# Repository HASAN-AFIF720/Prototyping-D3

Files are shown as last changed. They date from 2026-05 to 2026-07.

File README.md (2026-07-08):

# Prototyping-D3 — Autonomous 2WD Robot Vehicle






An **untethered, two-wheel-drive robot car** that operates as a hybrid **line follower** and **obstacle avoider**. The vehicle follows a strict safety-first priority: obstacle detection (safety) always overrides line tracking (navigation).

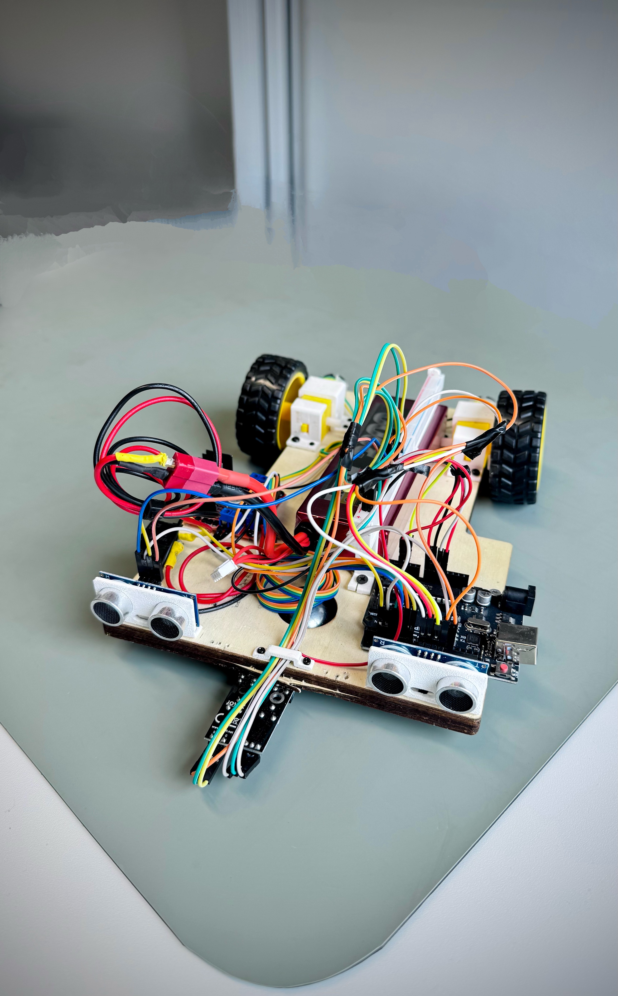
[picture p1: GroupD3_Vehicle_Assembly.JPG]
Assembled vehicle


---

## Overview

Built for the Systems Engineering / Prototyping module at **Hochschule Hamm-Lippstadt**, this project pairs a formal **SysML model** with a physically assembled Arduino prototype. Every loop follows a *Sense → Think → Act* pipeline: read the ultrasonic sensors first, and only fall through to IR line tracking when the path ahead is clear.

**Key features**

- Hybrid **line following + obstacle avoidance** on a single Arduino UNO
- **Safety-first priority gate** — obstacle avoidance pre-empts navigation every cycle
- **Dual HC-SR04** front sensors for obstacle detection and evasive manoeuvres
- **Dual downward IR** sensors for line tracking
- **Isolated power** — motor current separated from Arduino logic supply
- Full **SysML documentation** and **custom 3D-modeled mounts**

---

## Repository Structure

| Path | Contents |
|---|---|
| [`Codes/`](Codes) | Arduino firmware — 3 sketches (final, baseline, experimental) with its own README |
| [`Design/`](Design) | Mechanical CAD parts (STEP) with its own README |
| [`Diagrams/`](Diagrams) | **Current** SysML diagram set (7 PNGs) with its own README |
| `zz_diagrams_archive/` | Superseded diagrams — kept for history only, ignore (current set is in `Diagrams/`) |
| `GroupD3_Wiring_Schematic.pdf` | Full wiring / circuit schematic |
| `GroupD3_Vehicle_Assembly.JPG` | Photo of the assembled prototype |

---

## Hardware Architecture

| Component | Part | Role |
|---|---|---|
| Microcontroller | 1× Arduino UNO (Joy-IT), 5V logic | Central decision maker |
| Motor Driver | 1× L298N Dual H-Bridge | Drives motors; ENA/ENB jumpers removed for PWM |
| Actuators | 2× DC gear motors (rubber tread) | Left / right differential drive |
| Obstacle Sensors | 2× HC-SR04 ultrasonic | Front-Left / Front-Right distance |
| Tracking Sensors | 2× IR line sensors | Downward-facing line detection |
| Power | 12V / AA battery pack | Motor power isolated from logic power |

### Pin Map

| Subsystem | Signal | Arduino Pin |
|---|---|---|
| IR line sensor — Left | digital | D12 |
| IR line sensor — Right | digital | D13 |
| Right motor | ENA (PWM) / IN1 / IN2 | D10 / D5 / D4 |
| Left motor | ENB (PWM) / IN3 / IN4 | D11 / D7 / D6 |
| Ultrasonic — Left | TRIG / ECHO | A2 / A3 |
| Ultrasonic — Right | TRIG / ECHO | D2 / D3 |

> **IR polarity:** `HIGH` = line detected (consistent across all sketches). **Obstacle threshold:** 15 cm.

---

## Control Logic (Sense → Think → Act)

The `void loop()` executes a two-tier priority hierarchy:

**Priority 1 — Obstacle Avoidance (safety)**
Read both HC-SR04 sensors. If an obstacle is detected within the **15 cm** threshold, the vehicle halts and executes an evasive manoeuvre around the object, then re-acquires and rejoins the line before resuming.

**Priority 2 — Line Tracking (navigation)**
If the path is clear, read the IR sensors and correct course — turn toward the sensor that detects the line, or drive straight when centered.

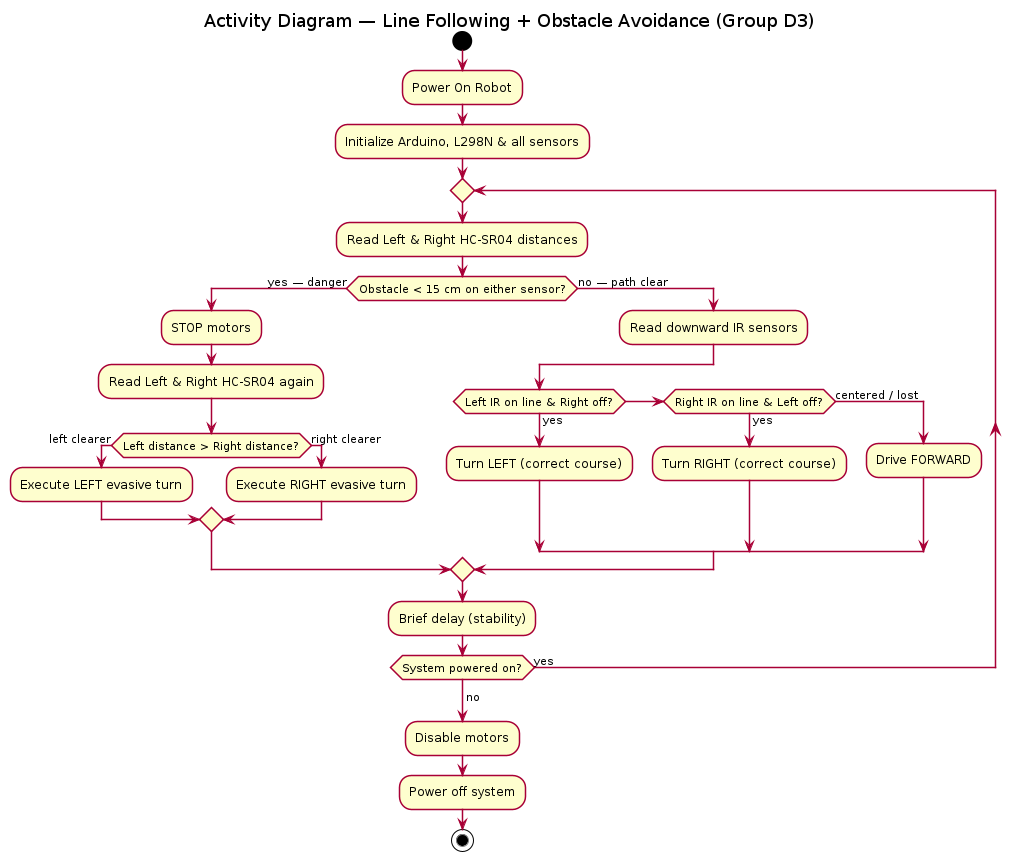
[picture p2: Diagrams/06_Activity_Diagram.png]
Control algorithm


Full behavioral and architectural models are in [`Diagrams/`](Diagrams): Requirement, BDD, IBD, Use Case, Sequence, Activity, and Package diagrams.

---

## Firmware — Build & Upload

All sketches live in [`Codes/`](Codes):

| Sketch | Purpose |
|---|---|
| `GroupD3_AutonomousVehicle_Final.ino` | **Final build** — line following + obstacle avoidance |
| `GroupD3_LineFollower_Baseline.ino` | Stable line-following baseline (Milestone 1) |
| `GroupD3_LineFollower_Fast_Experimental.ino` | Experimental higher-speed variant (reference only) |

**Steps** — requires the [Arduino IDE](https://www.arduino.cc/en/software) (1.8+ or 2.x):

1. Open `Codes/GroupD3_AutonomousVehicle_Final.ino` (the full build).
2. Select **Tools → Board → Arduino UNO**.
3. Select the correct **Port** under **Tools → Port**.
4. Wire the hardware per the Pin Map above (or `GroupD3_Wiring_Schematic.pdf`).
5. Power the L298N from the battery pack; **do not** back-feed motor voltage through the Arduino's USB.
6. Click **Upload**.

**Bench-test tips**

- Verify IR sensor polarity before driving — inverted line logic is the most common failure mode here.
- Confirm ultrasonic timing is intact (avoid Timer0 modifications, which distort `delay()`/`pulseIn()` used by HC-SR04).
- Test line following and obstacle avoidance in isolation before running the hybrid loop.

---

## Documentation

| Document | Location |
|---|---|
| Firmware (Arduino) | [`Codes/`](Codes) |
| SysML diagram set (7) | [`Diagrams/`](Diagrams) |
| Mechanical CAD (STEP) | [`Design/`](Design) |
| Circuit schematic | `GroupD3_Wiring_Schematic.pdf` |

---

## Project Milestones

- **Milestone 1 — Lane Following** ✅ Vehicle follows the track via IR line detection.
- **Milestone 2 — Obstacle Avoidance** ✅ HC-SR04 avoidance layered on the confirmed line-following base.

---

## Team — Group D3

| Member | GitHub |
|---|---|
| Md Afif Hasan | [@HASAN-AFIF720](https://github.com/HASAN-AFIF720) |
| Jubayer Ahmed | [@MainReturn0](https://github.com/MainReturn0) |
| Rei Halilaj | [@ReiHalilaj](https://github.com/ReiHalilaj) |
| Ambrose Alakweojimba |[@AmbroseDera](https://github.com/AmbroseDera)|

*Systems Engineering / Prototyping project — Hochschule Hamm-Lippstadt*

---

## License

Academic coursework, shared for educational reference. If you intend to reuse this work, please credit Group D3 and consider adding an explicit open-source license (e.g. MIT) to the repository.

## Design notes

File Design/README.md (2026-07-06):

# Prototyping-D3 — Mechanical Design (CAD)

This folder contains the custom mechanical parts for **Group D3's autonomous 2WD robot vehicle**, exported as **STEP** (ISO 10303) 3D models.

These parts are purpose-designed mounts rather than a generic kit chassis. The design goal is **alignment repeatability**: sensors sit exactly where the firmware expects them, and the motors are held rigid so the wheels react predictably. A stable mechanical base directly simplifies the control algorithm — the IR sensors stay at a fixed height and spacing, and the ultrasonic sensors keep a consistent forward-facing angle.

---

## Part Index

| # | File | Qty | Format | Purpose |
|---|---|-----|---|---|
| 1 | `GroupD3_2xIRSensor_6May2026.STEP` | 2 | STEP | Downward-facing IR line-sensor brackets (Left / Right) |
| 2 | `GroupD3_2xMotorholderPart1_6May2026.step` | 2 | STEP | DC gear-motor clamp — part 1 (Left / Right) |
| 3 | `GroupD3_2xMotorholderPart2_6May2026.step` | 2 | STEP | DC gear-motor clamp — part 2 (Left / Right) |
| 4 | `GroupD3_2xUltrasonicSensor_6May2026.STEP` | 2 | STEP | HC-SR04 ultrasonic mounts (Front-Left / Front-Right) |
| 5 | `GroupD3_8xPCBStandoff_6May2026.STEP` | 8 | STEP | Standoffs isolating and elevating the controller / driver boards |

**Total: 16 printed parts.** All exports dated 6 May 2026.

---

## Part Details

### 1 — IR Sensor Brackets (2×)
Hold the two IR line-tracking modules downward-facing at the front edge of the chassis. A fixed, equal ride-height on both sides keeps the digital line readings symmetric, which is what the steering-correction logic assumes.

### 2 & 3 — Motor Holder (2× Part 1 + 2× Part 2)
A two-piece clamp per motor that captures the DC gear motor body and bolts it rigidly to the chassis. Rigid mounting prevents the motor from shifting under load or during hard-reverse turns, protecting wheel alignment and reducing skid.

### 4 — Ultrasonic Sensor Mounts (2×)
Position the two HC-SR04 sensors at the front corners (Front-Left / Front-Right) with a consistent forward orientation, so the left/right distance comparison used for evasive turns stays meaningful.

### 5 — PCB Standoffs (8×)
Elevate and space the Arduino UNO and L298N driver above the chassis deck, keeping solder joints and pin headers clear of the surface and separating the logic board from the motor-driver board for cleaner wiring and easier fault checking.

---

## Mounts → Hardware Mapping

| Mechanical Part | Mounts | Electrical Interface |
|---|---|---|
| IR Sensor Bracket | 2× IR line sensor | D12 (Left), D13 (Right) |
| Motor Holder (P1 + P2) | 2× DC gear motor | via L298N: EN D10/D11, IN D4–D7 |
| Ultrasonic Mount | 2× HC-SR04 | A2/A3 (Left), D2/D3 (Right) |
| PCB Standoff | Arduino UNO + L298N | — |

---

## How to Open / Manufacture

STEP is a neutral CAD exchange format and opens in any MCAD tool:

- **FreeCAD** (free, open source), **Autodesk Fusion 360**, **Onshape**, **SolidWorks** — for viewing, editing, or re-exporting.
- **Online:** any browser-based STEP/glTF viewer for a quick look without installing software.

To fabricate, import the STEP file, orient the part, and export a mesh (`.STL` / `.3MF`) for your slicer. STL exports also preview directly in GitHub's built-in 3D viewer if you add them to the repo.

---

## Team — Group D3

MD Afif Hasan · Rei Halilaj · Ambrose · Jubayer Ahmed

*Systems Engineering / Prototyping project — Hochschule Hamm-Lippstadt*

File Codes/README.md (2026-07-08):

# Prototyping-D3 — Firmware (Arduino Sketches)

This folder contains the Arduino C++ firmware for **Group D3's autonomous 2WD robot vehicle**. Three sketches are kept here, tracking the project from a stable line-following baseline to the final hybrid line-following + obstacle-avoidance build.

> **For grading, open `GroupD3_AutonomousVehicle_Final.ino`** — it is the complete, submission version.

---

## Sketch Index

| File | Role | Milestone |
|---|---|---|
| `GroupD3_AutonomousVehicle_Final.ino` | **Final submission** — hybrid line following + ultrasonic obstacle avoidance | Milestone 2 |
| `GroupD3_LineFollower_Baseline.ino` | Stable, confirmed-working line follower (the base the final builds on) | Milestone 1 |
| `GroupD3_LineFollower_Fast_Experimental.ino` | Experimental higher-speed line-following variant (reference only, not graded) | — |

---

## `GroupD3_AutonomousVehicle_Final.ino` — Final Build

The complete vehicle firmware. It runs a *Sense → Think → Act* loop with a strict **safety-first priority**: obstacle avoidance is evaluated first every cycle and pre-empts line tracking.

```
loop():
  update ultrasonic readings
  read line sensors
  if obstacle detected  ->  avoid obstacle, then return   // safety first
  else                  ->  follow line                    // navigation
```

- **Line following:** proportional (KP) steering with signal filtering, dead-zone, and corner detection for smooth tracking and reliable cornering.
- **Obstacle avoidance:** triggers at the **15 cm** safety threshold, executes a timed evasive manoeuvre around the object, then re-acquires and rejoins the line. Includes distinct handling for a second obstacle (timed spin, spin-until-line, realign, resume).
- **Robust sensing:** ultrasonic reads use an echo timeout and a post-avoidance cooldown to reject spurious triggers.

## `GroupD3_LineFollower_Baseline.ino` — Stable Baseline

Pure IR line following with no obstacle sensing — the confirmed-working foundation (Milestone 1). Uses a dual-speed strategy (full speed on straights, reduced speed on curves) with a hard-reverse inner wheel for reliable turns, and raises the motor PWM frequency for smooth low-speed control. This is the known-good reference the final build extends.

## `GroupD3_LineFollower_Fast_Experimental.ino` — Experimental

A higher-speed line-following variant retained for reference. It is **not** the graded build and may behave less predictably at speed.

---

## Hardware & Pin Map

All sketches target an **Arduino UNO** driving an **L298N** dual H-bridge (ENA/ENB jumpers removed for PWM).

| Subsystem | Signal | Pin |
|---|---|-----|
| IR line sensor — Left | digital | D12 |
| IR line sensor — Right | digital | D13 |
| Right motor | ENA (PWM) / IN1 / IN2 | D10 / D5 / D4 |
| Left motor | ENB (PWM) / IN3 / IN4 | D11 / D7 / D6 |
| Ultrasonic — Left | TRIG / ECHO | A2 / A3 |
| Ultrasonic — Right | TRIG / ECHO | D2 / D3 |

**IR polarity:** `HIGH` = line detected. **Obstacle threshold:** 15 cm.

---

## Build & Upload

1. Open the sketch in the [Arduino IDE](https://www.arduino.cc/en/software) (1.8+ or 2.x).
2. **Tools → Board → Arduino UNO**, then select the correct **Port**.
3. Power the L298N from the battery pack; do **not** back-feed motor voltage through the Arduino's USB.
4. **Upload**.

> Tip: in the Arduino IDE a `.ino` is expected to sit in a folder of the same name. If the IDE prompts to create one when opening, allow it — it does not change the code.

---

*Group D3 — Systems Engineering / Prototyping, Hochschule Hamm-Lippstadt*

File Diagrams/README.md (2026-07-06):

# Prototyping-D3 — Systems Engineering (SysML) Documentation

This folder contains the SysML model set for **Group D3's autonomous 2WD robot vehicle**: an untethered, battery-powered car that operates as a hybrid **line follower** and **obstacle avoider**.

The system follows a strict **safety-first priority**: obstacle detection (safety) always overrides line tracking (navigation). Each loop executes a *Sense → Decide → Act* pipeline — read the ultrasonic sensors first, and only fall through to IR line tracking when the path ahead is clear.

---

## Diagram Index

| # | Diagram | Purpose |
|---|---|---|
| 01 | Requirement Diagram | Autonomous-operation requirement tree and hardware `«satisfy»` mapping |
| 02 | Block Definition Diagram (BDD) | System composition and part multiplicities |
| 03 | Internal Block Diagram (IBD) | Internal signal/power connectors with Arduino pin allocation |
| 04 | Use Case Diagram | Operator interactions and parallel scan/track behaviors |
| 05 | Sequence Diagram | Runtime timeline of one navigation loop |
| 06 | Activity Diagram | `void loop()` control flow as an if/else flowchart |
| 07 | Package Diagram | Firmware architecture (config, drivers, control logic, main) |

---

## 01 — Requirement Diagram

Captures the top-level requirement **REQ-1.0 (Autonomous Operation)** and its decomposition into obstacle avoidance, line tracking, untethered power, and the 15 cm safety threshold. Each hardware block is linked to the requirement it satisfies.

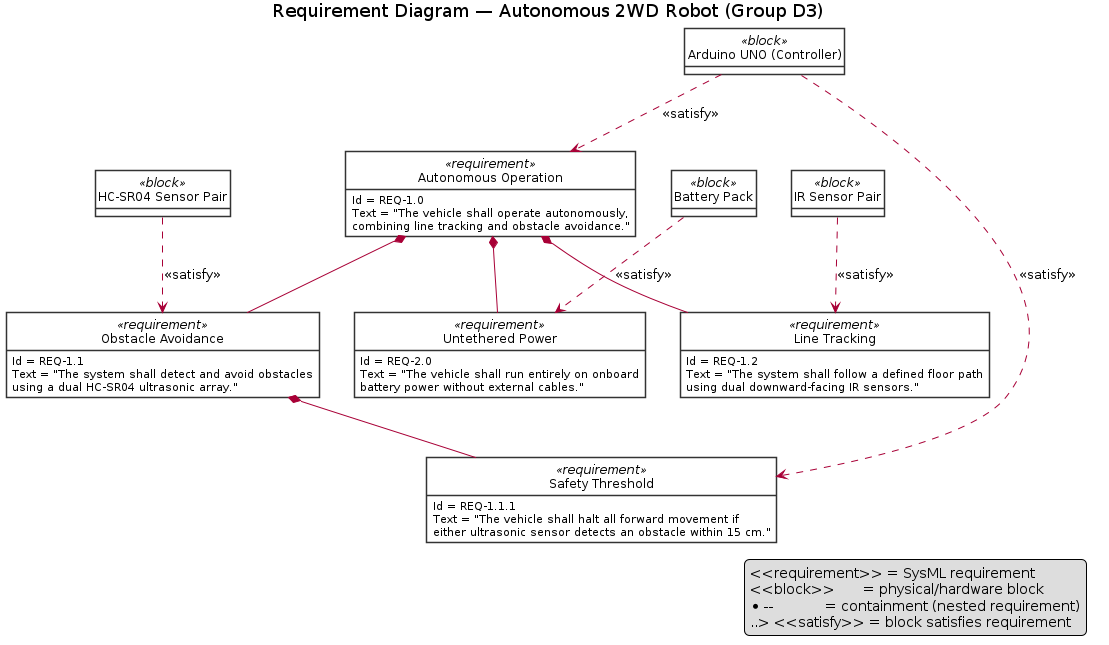
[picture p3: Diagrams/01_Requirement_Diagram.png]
Requirement Diagram


## 02 — Block Definition Diagram (BDD)

Defines the vehicle as a composition of its blocks — controller, motor driver, motors, sensors, battery, and chassis — with multiplicities (2× HC-SR04, 2× IR, 2× DC gear motors).

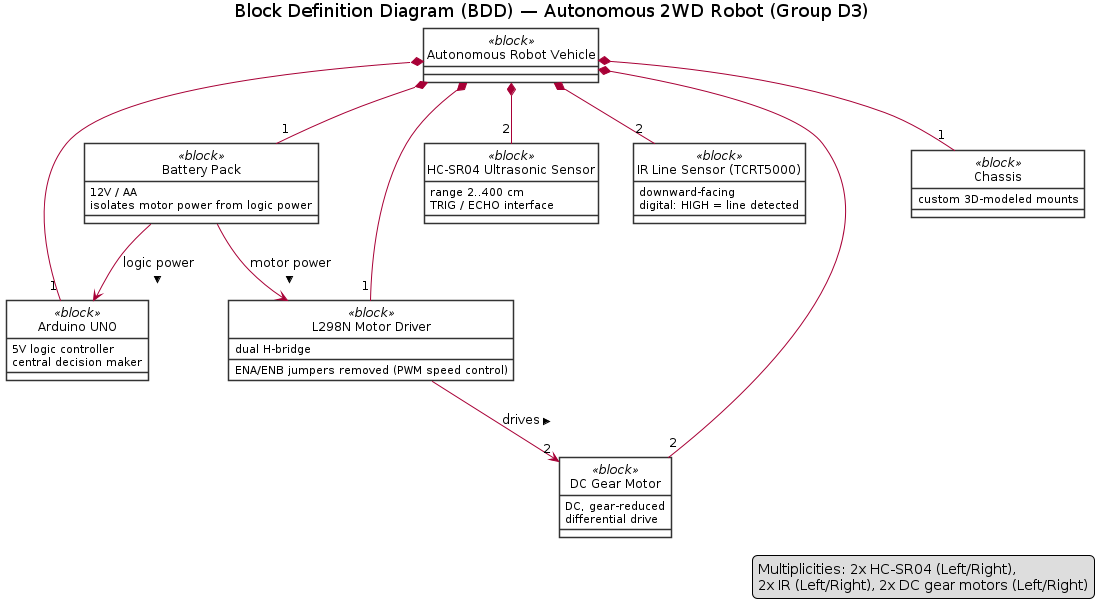
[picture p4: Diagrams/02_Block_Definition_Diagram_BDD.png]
Block Definition Diagram


## 03 — Internal Block Diagram (IBD)

Shows the internal wiring: power distribution from the battery and control/sensing connectors between the Arduino, L298N driver, motors, and both sensor pairs, annotated with the physical pin assignments.

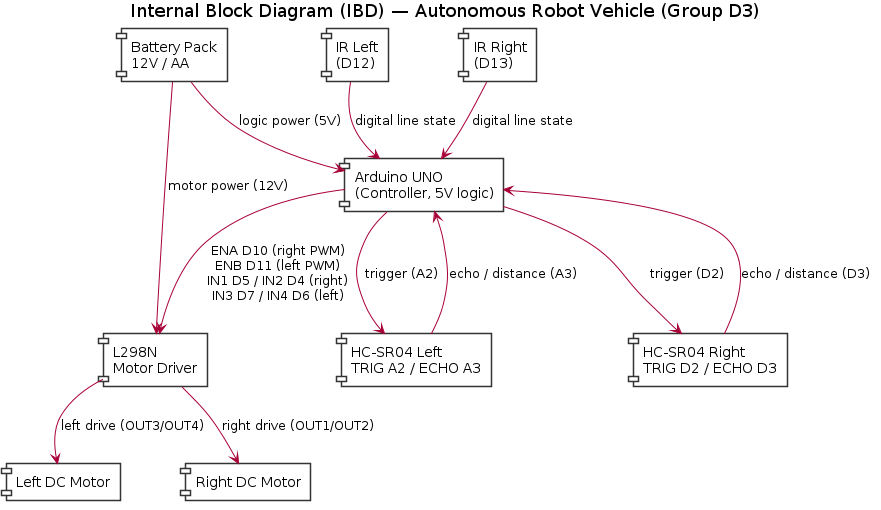
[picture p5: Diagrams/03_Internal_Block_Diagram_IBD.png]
Internal Block Diagram


## 04 — Use Case Diagram

Models the System Operator's interactions (power-on, start navigation, emergency stop) and the internal `«include»` / `«extend»` behaviors for line tracking and obstacle scanning.

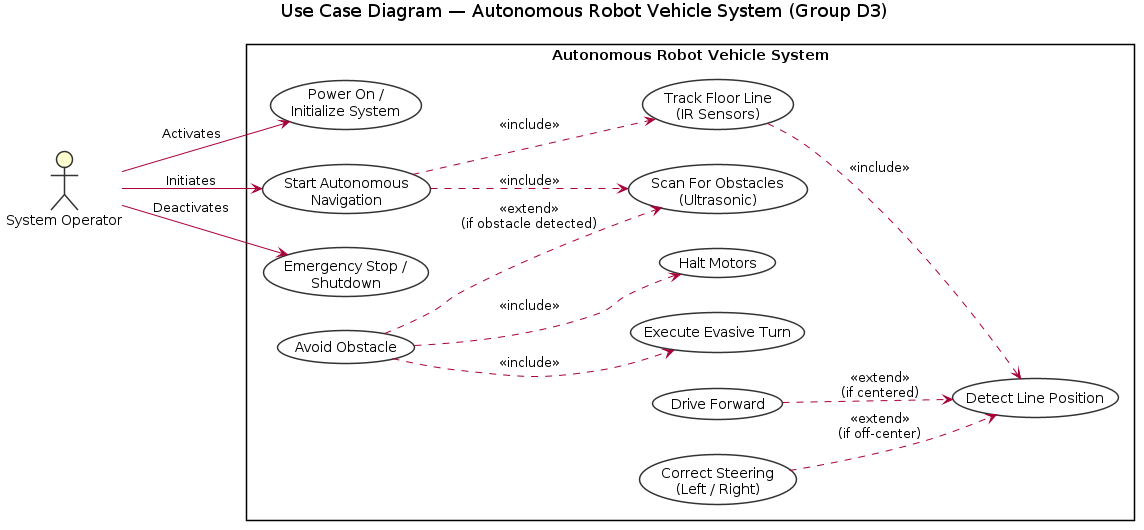
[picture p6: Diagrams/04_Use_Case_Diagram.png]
Use Case Diagram


## 05 — Sequence Diagram

Details the message timeline of a single autonomous navigation loop, including the safety-priority branch (halt → compare distances → evasive turn) and the motor-power request handshake with the battery.

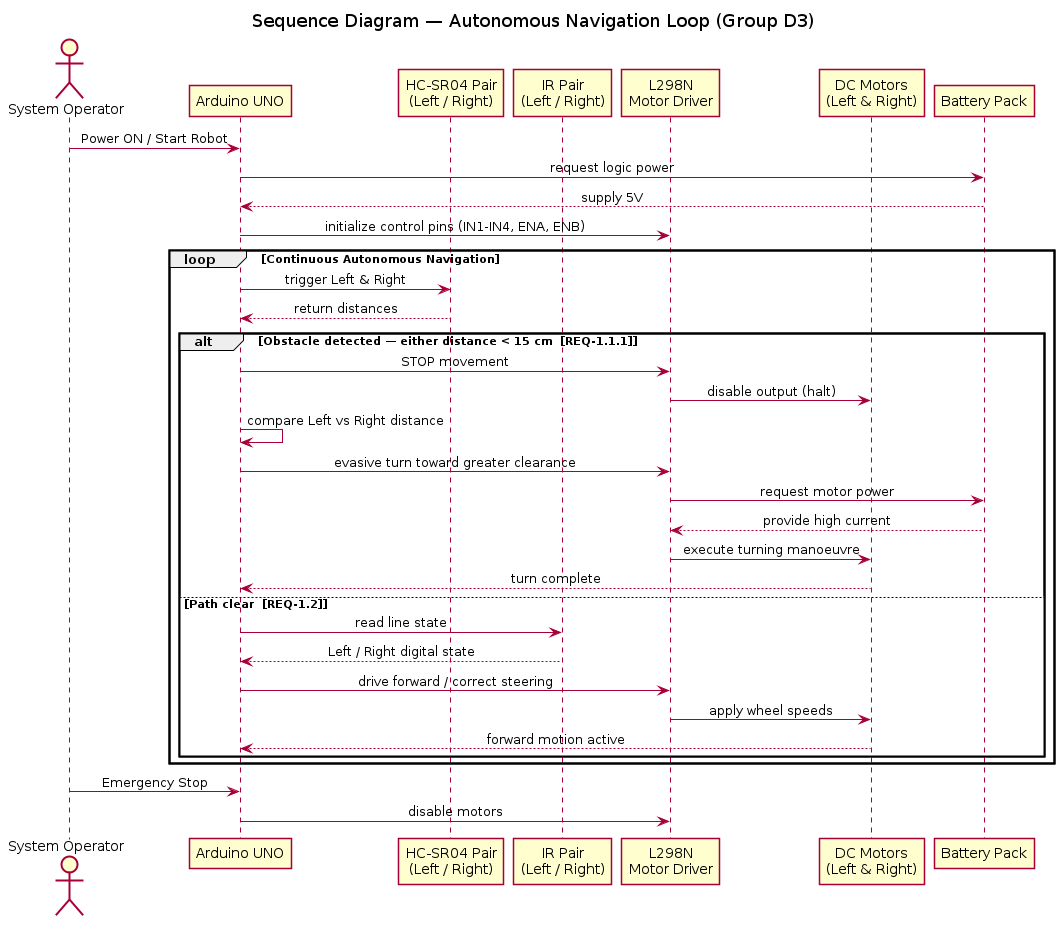
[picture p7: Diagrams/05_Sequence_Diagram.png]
Sequence Diagram


## 06 — Activity Diagram

The algorithmic flowchart of `void loop()`: the safety-first gate that reads both ultrasonic sensors, halts and turns toward the greater clearance on detection, and otherwise falls through to IR-based line correction.

Activity Diagram

## 07 — Package Diagram

The firmware's software architecture, separating the Arduino core library from the project's Config, Drivers, Control Logic, and Main packages.

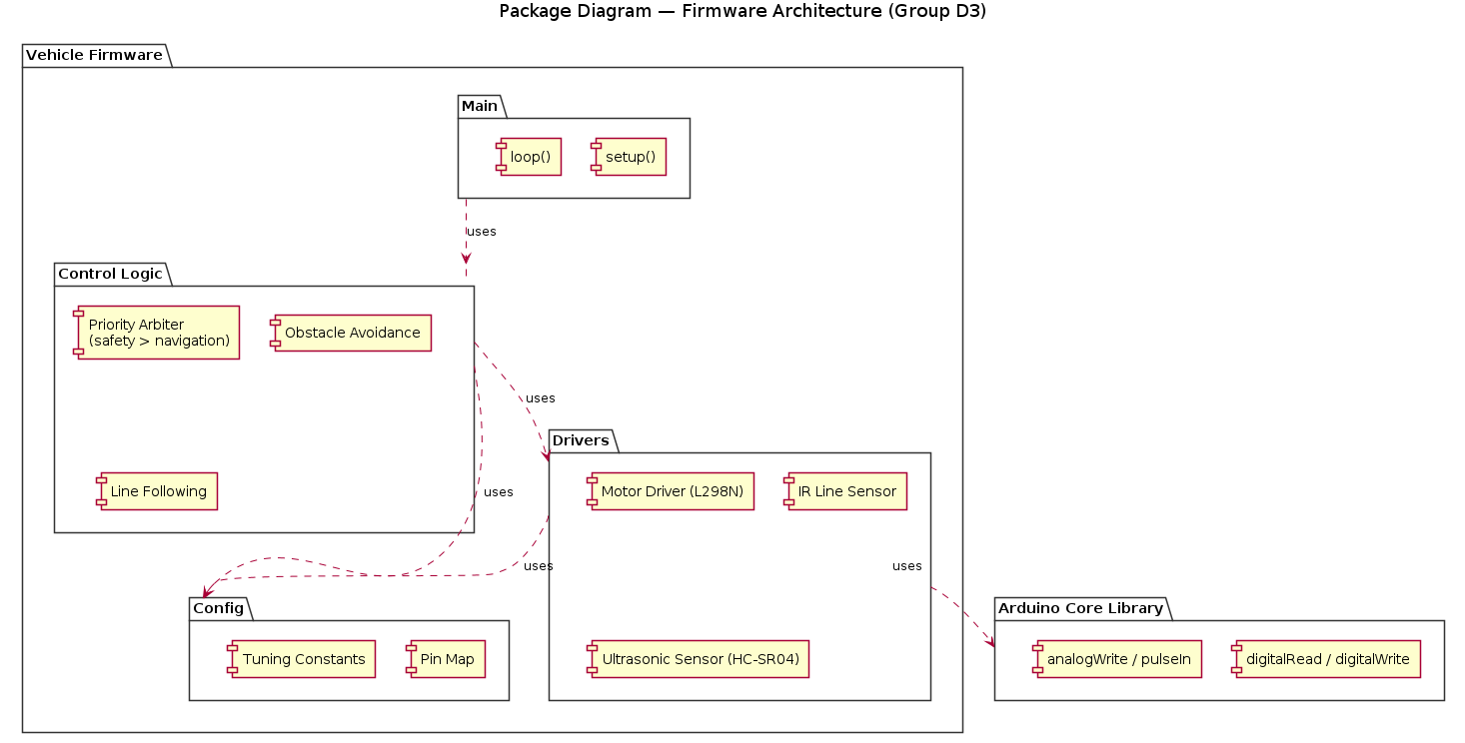
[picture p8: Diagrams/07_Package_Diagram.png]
Package Diagram


---

## Hardware Reference

| Subsystem | Signal | Arduino Pin |
|---|---|---|
| IR line sensor — Left | digital | D12 |
| IR line sensor — Right | digital | D13 |
| Right motor | ENA (PWM) / IN1 / IN2 | D10 / D5 / D4 |
| Left motor | ENB (PWM) / IN3 / IN4 | D11 / D7 / D6 |
| Ultrasonic — Left | TRIG / ECHO | A2 / A3 |
| Ultrasonic — Right | TRIG / ECHO | D2 / D3 |

**Core platform:** Arduino UNO (5V logic) · L298N dual H-bridge (ENA/ENB jumpers removed for PWM) · 2× DC gear motors · 2× HC-SR04 · 2× IR line sensors · 12V/AA battery pack (motor power isolated from logic). Obstacle safety threshold: **15 cm**.

---

## Requirements Traceability

| ID | Requirement | Satisfied By |
|----|---|---|
| REQ-1.0 | Operate autonomously, combining line tracking and obstacle avoidance | Arduino UNO |
| REQ-1.1 | Detect and avoid obstacles using a dual HC-SR04 array | HC-SR04 sensor pair |
| REQ-1.1.1 | Halt all forward movement if either sensor detects an obstacle within 15 cm | Arduino UNO + HC-SR04 pair |
| REQ-1.2 | Follow a defined floor path using dual downward-facing IR sensors | IR sensor pair |
| REQ-2.0 | Run entirely on onboard battery power without external cables | Battery pack |

---

## Team — Group D3

MD Afif Hasan · Rei Halilaj · Ambrose · Jubayer Ahmed

*Systems Engineering / Prototyping project — Hochschule Hamm-Lippstadt*

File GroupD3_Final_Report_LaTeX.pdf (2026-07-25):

Hochschule Hamm-Lippstadt

Systems Engineering & Prototyping

# Autonomous 2WD Robot Vehicle

### A Hybrid Line-Following and Obstacle-Avoiding System

Final Milestone — Project Submission

Group: | D3
Team: | Md Afif Hasan Rei Halilaj Ambrose Jubayer Ahmed
Supervisor: | Faezeh Pasandideh
Date: | July 2026

Repository: github.com/HASAN-AFIF720/Prototyping-D3

Autonomous 2WD Robot Vehicle | Group D3

### Abstract

This report documents the design, modelling, and implementation of an autonomous, untethered two-wheel-drive (2WD) robot vehicle developed as a Systems Engineering prototyping project. The vehicle combines two behaviours on a single Arduino UNO: infrared (IR) line following for navigation and ultrasonic obstacle avoidance for safety. A strict priority hierarchy governs the control loop — obstacle avoidance always pre-empts line tracking. The work is grounded in a formal SysML model (requirement, block, use case, sequence, activity, and package diagrams) that traces every hardware block back to a defined requirement. The prototype was assembled on a custom 3D-modelled chassis and validated through incremental bench testing. This document presents the full engineering process from requirements to a tested prototype, satisfying both project milestones: lane following (Milestone 1) and obstacle avoidance (Milestone 2).

### Contents

Abstract | 1
1 Introduction | 2
2 Requirements Engineering | 2
3 System Architecture | 3
4 Behavioural Modelling | 5
5 Control Algorithm | 8
6 Firmware Implementation | 8
7 Testing and Results | 9
8 Challenges and Solutions | 10
9 Project Management | 10
10 Conclusion and Future Work | 11
Team Contributions | 12

### 1 Introduction

### 1.1 Motivation

Autonomous driving is a key enabler for the future of mobility, relying on the coordinated operation of perception, decision-making, and actuation. Autonomous routing, obstacle detection, and parking are representative capabilities of such systems. This project miniaturises that challenge into a tabletop robot: a vehicle that must perceive a track and its surroundings, decide on a safe action, and actuate its motors accordingly — all without human intervention or a physical tether.

### 1.2 Objectives and Scope

The system was required to autonomously drive along a defined track using line detection while detecting and avoiding obstacles in its path. The scope of the final milestone comprises:
- A complete SysML systems-engineering model.
- A physically assembled, untethered prototype.
- Embedded firmware implementing the priority-based control logic.
- Incremental validation of both behaviours on hardware.

### 1.3 Milestones

The project was structured around two deliverable milestones:
- Milestone 1 — Lane Following: the vehicle follows the track via IR line detection.
- Milestone 2 — Obstacle Avoidance: ultrasonic obstacle avoidance layered on the confirmed line-following base.

### 2 Requirements Engineering

The analysis began by capturing system requirements and mapping each to the hardware block that satisfies it. Figure 1 shows the SysML requirement diagram: a top-level autonomousoperation requirement decomposes into obstacle avoidance, line tracking, untethered power, and a nested safety threshold.


Figure 1: SysML Requirement Diagram with block satisfy relationships.

Table 1: Requirements traceability.

ID | Requirement | Statement | Satisfied by
REQ-1.0 | Autonomous Operation Operate autonomously, combining line
| | tracking and obstacle avoidance. | Arduino UNO
REQ-1.1 | Obstacle Avoidance | Detect and avoid obstacles using a dual HC-SR04 ultrasonic array. | HC-SR04 pair
REQ-1.1.1 Safety Threshold | Halt all forward movement if either sen-
| | sor detects an obstacle within 15 cm. | Arduino + HC-SR04
REQ-1.2 | Line Tracking | Follow a defined floor path using dual downward-facing IR sensors. | IR sensor pair
REQ-2.0 | Untethered Power | Run entirely on onboard battery power without external cables. | Battery pack

### 3 System Architecture

### 3.1 Hardware Composition

The vehicle is composed of a controller, a motor driver, two actuators, two sensor pairs, a battery, and a custom chassis. The Block Definition Diagram (Figure 2) captures this composition and its multiplicities.

Table 2: Bill of materials.

Component | Part | Role
Microcontroller | 1× Arduino UNO (5V logic) | Central decision maker
Motor Driver | 1× L298N dual H-bridge | PWM motor control (ENA/ENB jumpers re-
| | moved)
Actuators | 2× DC gear motors | Left/right differential drive
Obstacle Sensors | 2× HC-SR04 | Front-left / front-right distance
Tracking Sensors | 2× IR line sensors | Downward-facing line detection
Power | 12V / AA battery pack | Motor power isolated from logic
Chassis | Custom 3D-modelled parts | Mounts and structure


Figure 2: Block Definition Diagram (BDD) — system composition and multiplicities.

### 3.2 Internal Structure and Pin Allocation

The Internal Block Diagram (Figure 3) details the power and signal connectors between blocks, annotated with the Arduino pin allocation summarised in Table 3.

Table 3: Pin map (as flashed).

Subsystem | Signal | Arduino Pin
IR line sensor — Left | digital | D12
IR line sensor — Right digital | D13
Right motor | ENA (PWM) / IN1 / IN2 D10 / D5 / D4
Left motor | ENB (PWM) / IN3 / IN4 | D11 / D7 / D6
Ultrasonic — Left | TRIG / ECHO | A2 / A3
Ultrasonic — Right | TRIG / ECHO | D2 / D3


Figure 3: Internal Block Diagram (IBD) — pin-level connectors.

### 3.3 Circuit / Wiring

Figure 4 shows the full wiring schematic. Power flows from the battery to the L298N (12V) and, via the Arduino’s regulated 5V rail, to the sensors; a common ground ties the driver, controller, and sensors together.

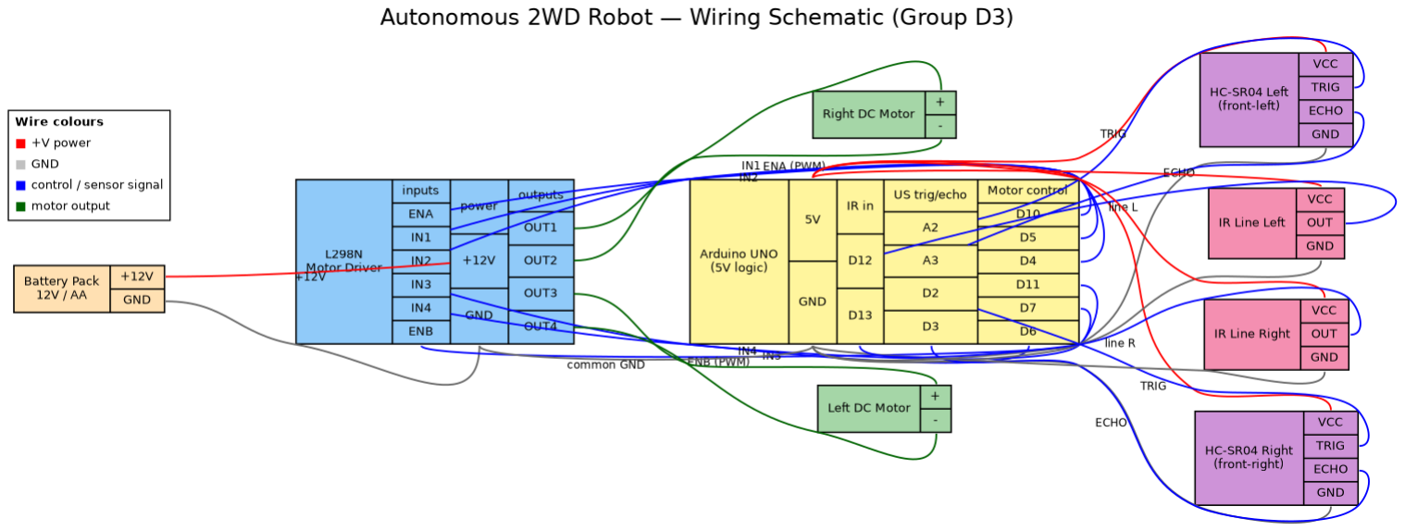
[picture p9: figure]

Figure 4: Circuit wiring schematic (colour-coded: power, ground, signal, motor output).

### 4 Behavioural Modelling

### 4.1 Use Cases

The operator interacts with the system through three use cases — power-on, start navigation, and emergency stop. Navigation includes both line tracking and obstacle scanning, which in turn extend into steering corrections and evasive turns (Figure 5).

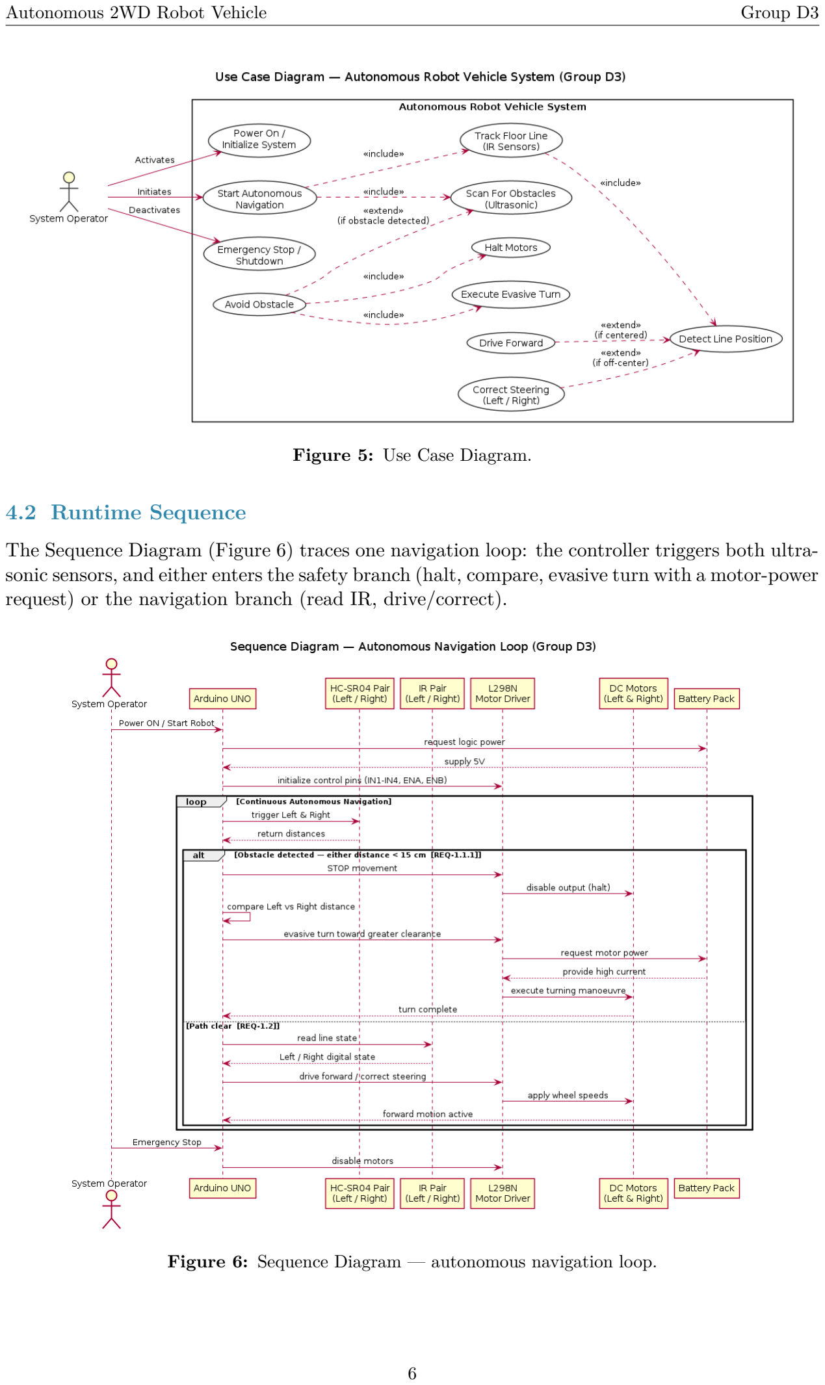
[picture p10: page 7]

Figure 5: Use Case Diagram.

### 4.2 Runtime Sequence

The Sequence Diagram (Figure 6) traces one navigation loop: the controller triggers both ultrasonic sensors, and either enters the safety branch (halt, compare, evasive turn with a motor-power request) or the navigation branch (read IR, drive/correct).

Figure 6: Sequence Diagram — autonomous navigation loop.

### 4.3 Control Activity

The Activity Diagram (Figure 7) expresses the loop() as an if/else flowchart with the safety-first gate.


Figure 7: Activity Diagram — line following and obstacle avoidance.

### 4.4 Software Architecture

The Package Diagram (Figure 8) separates the Arduino core library from the project’s configuration, drivers, control logic, and main packages.


Figure 8: Package Diagram — firmware architecture.

### 5 Control Algorithm

The firmware realises a Sense → Think → Act pipeline with a two-tier priority hierarchy. Safety (obstacle avoidance) is evaluated first every cycle; navigation (line tracking) runs only when the path ahead is clear.

1. Priority 1 — Obstacle Avoidance. Trigger both HC-SR04 sensors. If either distance is below the 15 cm threshold (REQ-1.1.1), halt the motors, compare the left and right distances, and execute an evasive turn toward the side with the greater open distance.
2. Priority 2 — Line Tracking. If the path is clear, read the IR sensors and correct course: turn toward the sensor that detects the line, or drive straight when centred.

### 6 Firmware Implementation

The firmware is written in Arduino C++ and organised into a low-level motor driver, sensor read routines, and the priority-gated main loop. Listing 1 shows the core control loop with SysML traceability comments; Listing 2 shows the signed-speed motor driver.

1 | // Sense -> Think -> Act , safety before navigation
2 | void loop () {
3 | long dL = readUltrasonic ( US_LEFT_TRIG , | US_LEFT_ECHO ) ;
4 | long dR = readUltrasonic ( US_RIGHT_TRIG , US_RIGHT_ECHO ) ;

5
6 | // ---- Priority 1: Obstacle Avoidance (REQ -1.1 , REQ -1.1.1) ----
7 | if ( dL < OBSTACLE_CM || dR < OBSTACLE_CM ) {
8 | stopMotors () ; | // halt on detection
9 | if ( dL >= dR ) pivotLeft () ; | // turn toward greater clearance
10 | else | pivotRight () ;
11 | return ; | // skip navigation this cycle
12 | }

13
14 | // ---- Priority 2: Line Tracking (REQ -1.2) ----
15 | int irLeft | = digitalRead ( IR_LEFT ) ;
16 | int irRight = digitalRead ( IR_RIGHT ) ;
17 | if | ( irLeft == LINE && irRight != LINE ) | turnLeft () ;
18 | else if ( irRight == LINE && irLeft != LINE ) | turnRight () ;

19 | else | driveForward () ;
20 | }

Listing 1: Priority-gated main loop (representative).

1 | // positive = forward , negative = reverse , 0 = brake
2 | void rotateMotor ( int rightSpeed , int leftSpeed ) {
3 | digitalWrite ( rightIn1 , rightSpeed > 0) ;
4 | digitalWrite ( rightIn2 , rightSpeed < 0) ;
5 | digitalWrite ( leftIn1 , | leftSpeed | > 0) ;
6 | digitalWrite ( leftIn2 , | leftSpeed | < 0) ;
7 | analogWrite ( enableRight , abs ( rightSpeed ) ) ;
8 | analogWrite ( enableLeft , | abs ( leftSpeed ) ) ;
9 | }

Listing 2: Signed-speed motor driver over the L298N.

A key implementation lesson concerned timer configuration: the PWM enable pins are governed by Timer1 and Timer2, so the Arduino default Timer0 must be left untouched — modifying it silently distorts delay() and pulseIn(), which the HC-SR04 timing depends on.

### 7 Testing and Results

Each behaviour was validated in isolation before integration, following the principle that a confirmed-working base is extended rather than rewritten. Table 4 summarises the outcomes.

Table 4: Validation summary.

Test | Criterion | Result
IR polarity check | Correct line vs. surface reading | Pass
Straight-line tracking Follows track without drift | Pass
Curve handling | Negotiates corners without departure Pass
Obstacle halt | Stops within 15 cm threshold | Pass
Evasive turn | Turns toward clearer side | Pass
Return to line | Resumes tracking after avoidance | Pass

Tuning focused on motor speeds: full speed on straights with automatic speed reduction on curves, and a hard-reverse inner wheel (at roughly 80% of the curve speed) as the middle ground between soft turns (which caused track departure) and full-reverse turns (which caused skid).

### 8 Challenges and Solutions

Table 5: Key challenges and how they were addressed.

Challenge | Solution
Choosing an effective chassis design | Evaluated multiple CAD designs before
| building.
Tangled / loose wiring during testing | Re-checked, labelled, and secured connec-
| tions.
Faulty Arduino and ultrasonic modules Replaced the affected controller and sensors.
Inverted IR line logic (recurring bug) | Bench-verified sensor polarity before build-
| ing on new code.
Ultrasonic timing corruption | Left Timer0 at default; used Timer1/Timer2
| for PWM.
Inconsistent multi-sensor behaviour | Debugged code in small modules before in-
| tegration.

### 9 Project Management

The team used a shared Git repository with continuous uploads of results and responsibilities. The overall task was divided per member by strengths across mechanical design, sensor logic, algorithm, and integration. Version numbers tracked firmware states so that a confirmed-working baseline was always preserved before new features were layered on top.

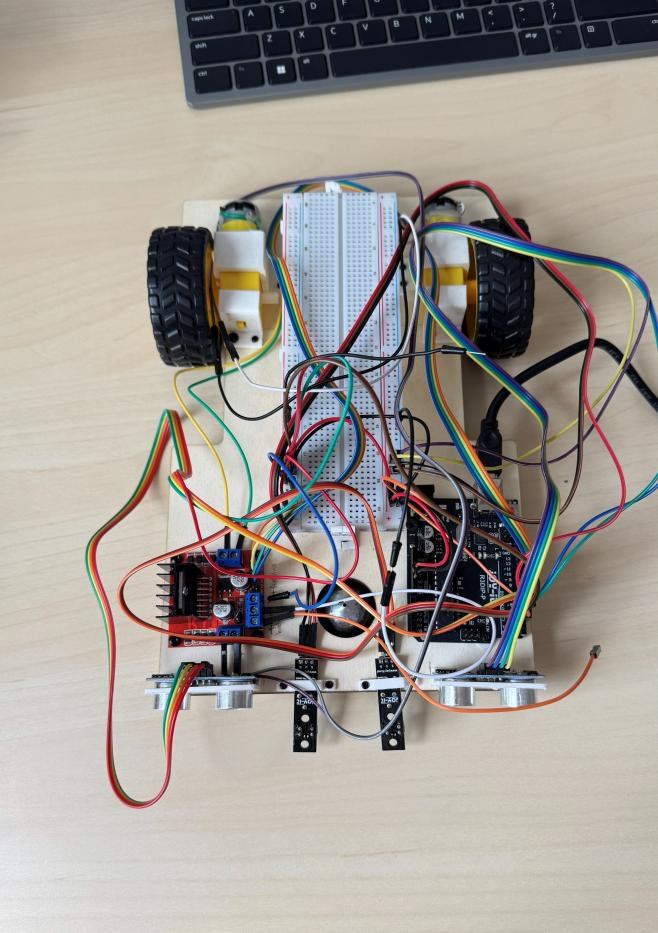
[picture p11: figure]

Figure 9: Top-down view of the assembled prototype showing sensor and module placement.

### 10 Conclusion and Future Work

The project delivered a fully modelled and physically realised autonomous 2WD vehicle that satisfies both milestones: reliable lane following and safety-first obstacle avoidance. The SysML model provided end-to-end traceability from requirements to firmware, and incremental bench testing confirmed correct behaviour. Future work could include a PID-based line controller for smoother tracking, a third forward sensor to reduce the blind spot between the two ultrasonic cones, and closed-loop speed control using wheel encoders.

### Team Contributions

Member | Primary Contribution
Md Afif Hasan | Scrum backlog, Hardware architecture, integration
Rei Halilaj | Sensor logic (IR and ultrasonic), Control algorithm and firmware
Jubayer Ahmed Mechanical design, firmware, GitHub and documentation
Ambrose | Testing, challenge analysis

### References

[1] Object Management Group, OMG Systems Modeling Language (SysML) Specification.
[2] Arduino, Arduino UNO Rev3 Documentation, arduino.cc.
[3] HC-SR04 Ultrasonic Ranging Module Datasheet.
[4] STMicroelectronics, L298 Dual Full-Bridge Driver Datasheet.

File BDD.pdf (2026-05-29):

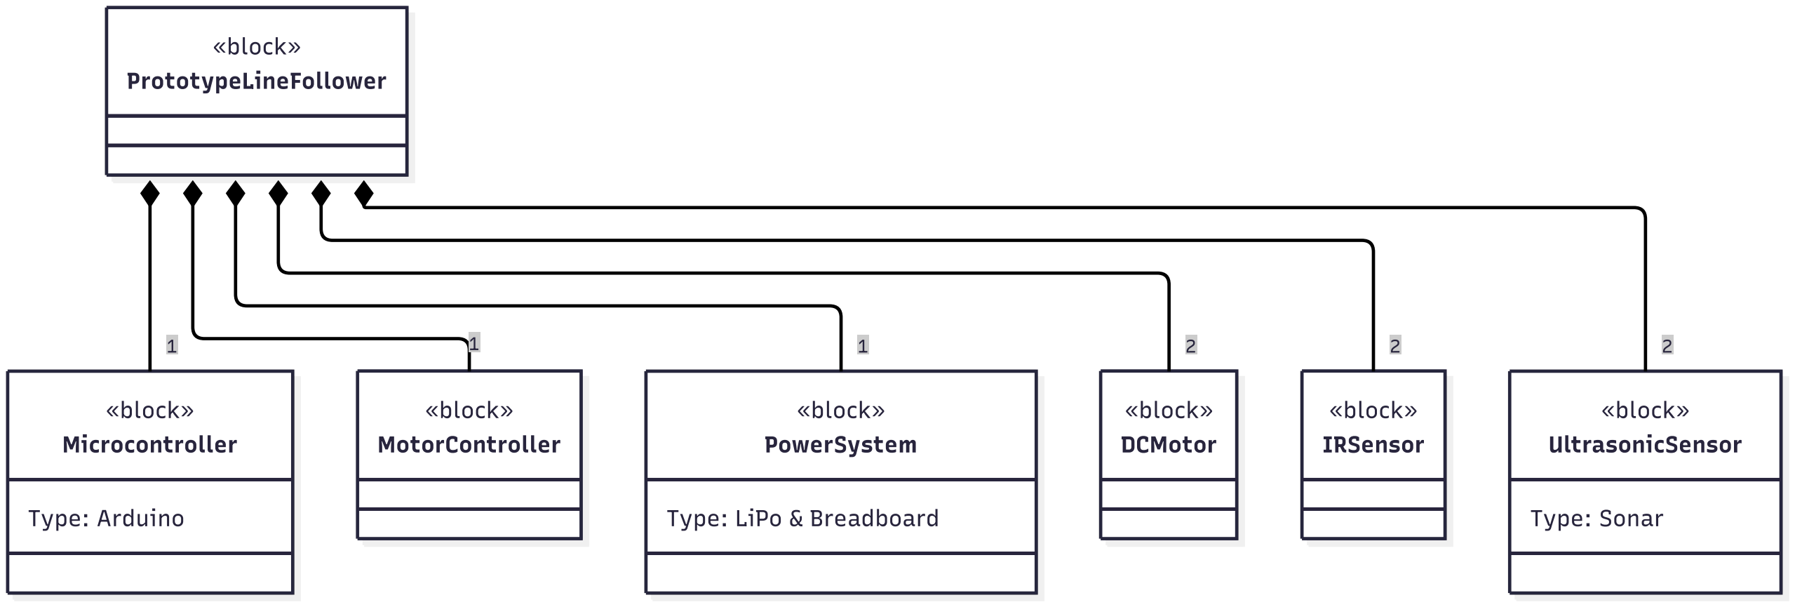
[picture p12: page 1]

«block»

PrototypeLineFollower

«block»

Microcontroller

Type: Arduino

«block»

MotorController

«block»

PowerSystem

Type: LiPo & Breadboard

«block»

DCMotor

«block»

IRSensor

«block»

UltrasonicSensor

Type: Sonar

1 | 1 | 1 | 2 | 2 | 2

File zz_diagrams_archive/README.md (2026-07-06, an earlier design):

Superseded — the current diagrams are in /Diagrams

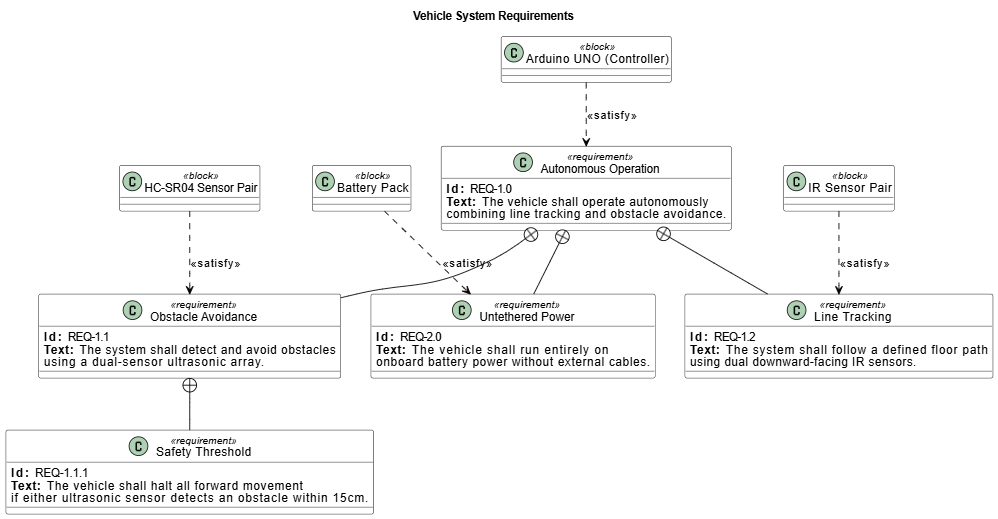
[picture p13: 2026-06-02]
Requirement_Diagram1.png

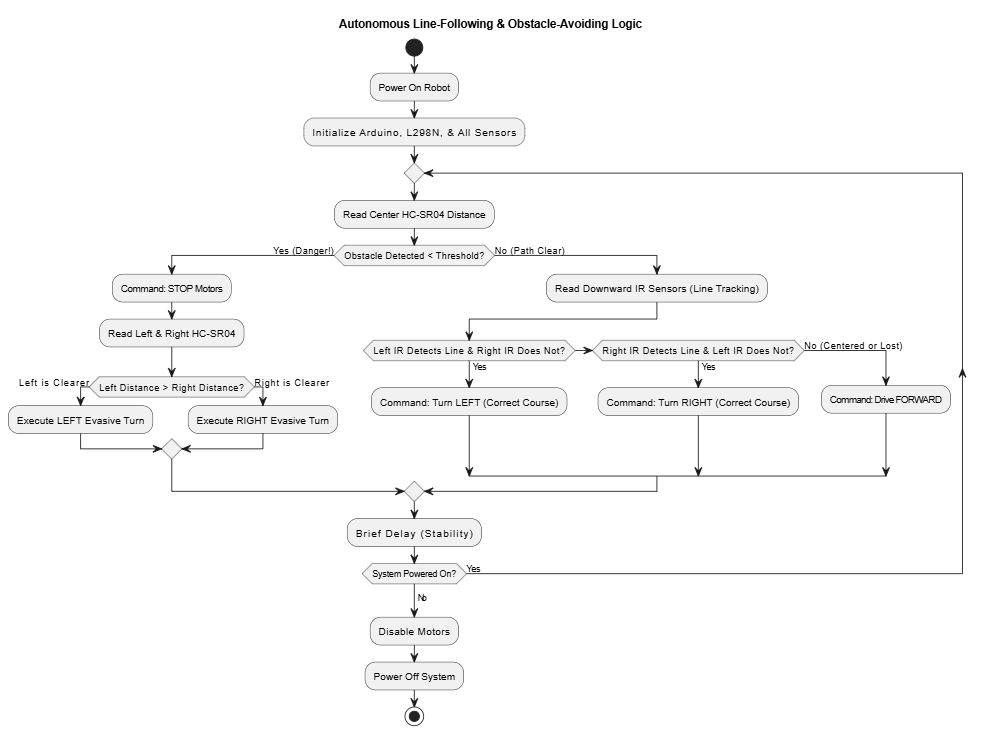
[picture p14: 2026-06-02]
Activity_Diagram.png

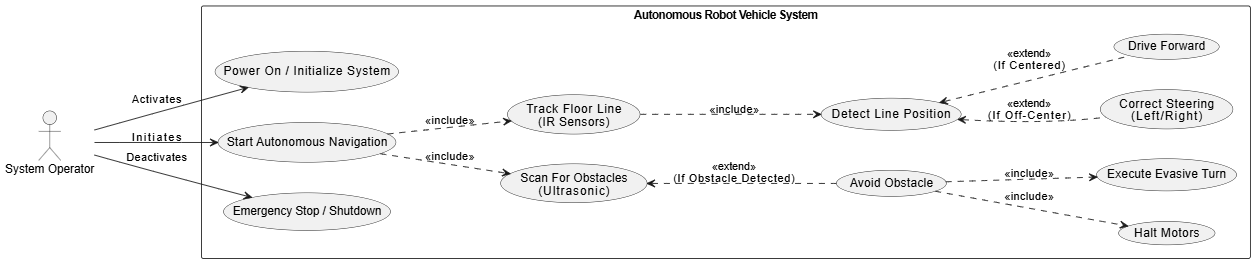
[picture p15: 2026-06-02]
Use_Case.png

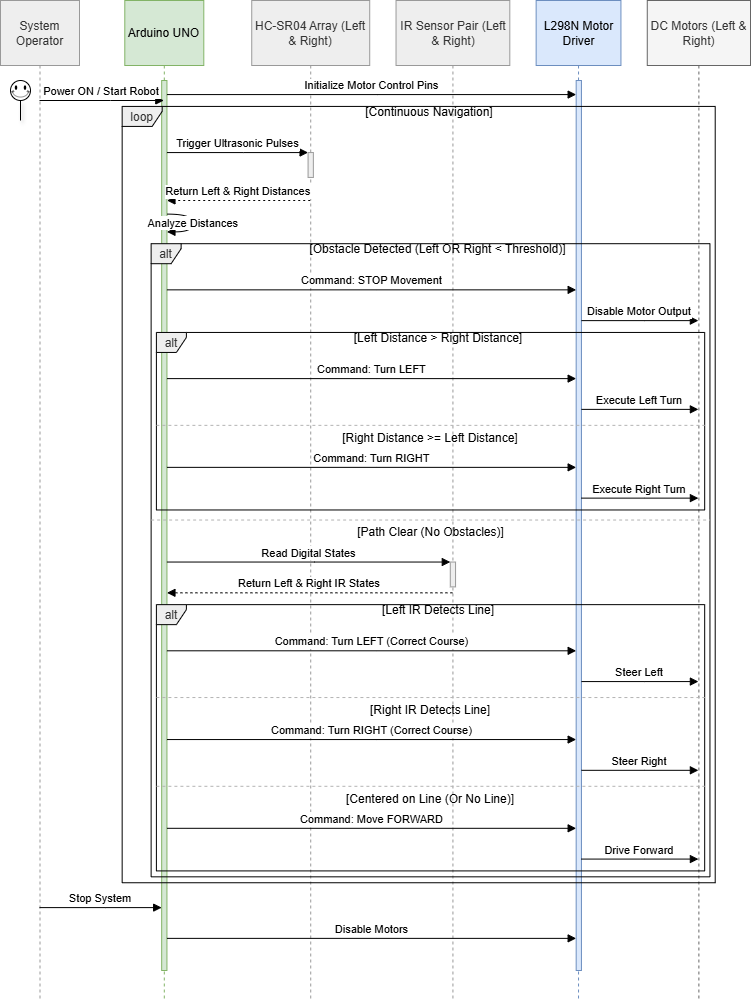
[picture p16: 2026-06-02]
Sequence_Diagram.png

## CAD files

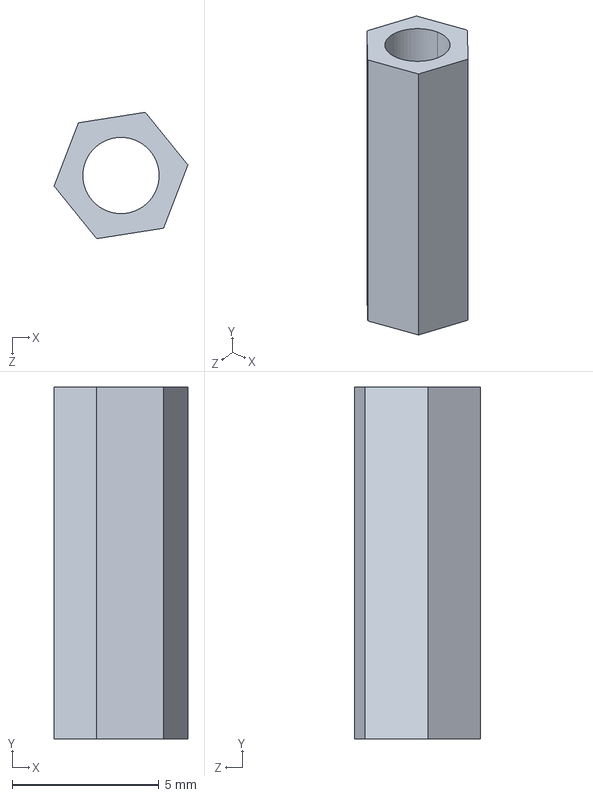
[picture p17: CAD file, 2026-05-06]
Design/GroupD3_8xPCBStandoff_6May2026.STEP
4.56 x 12.0 x 4.31 mm

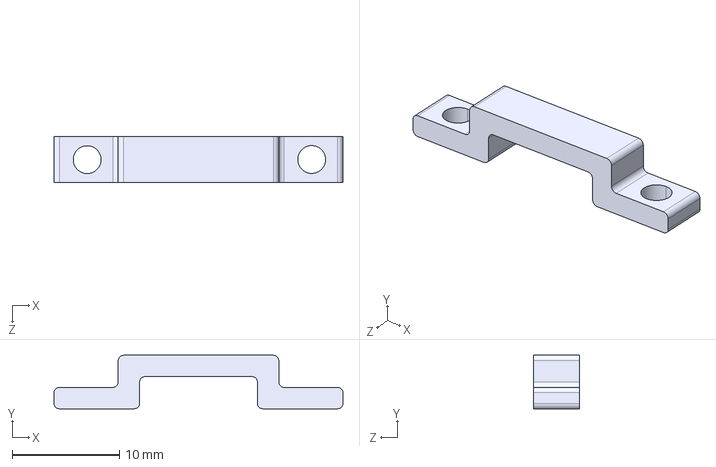
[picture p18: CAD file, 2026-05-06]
Design/GroupD3_2xIRSensor_6May2026.STEP
27.0 x 5.00 x 4.30 mm

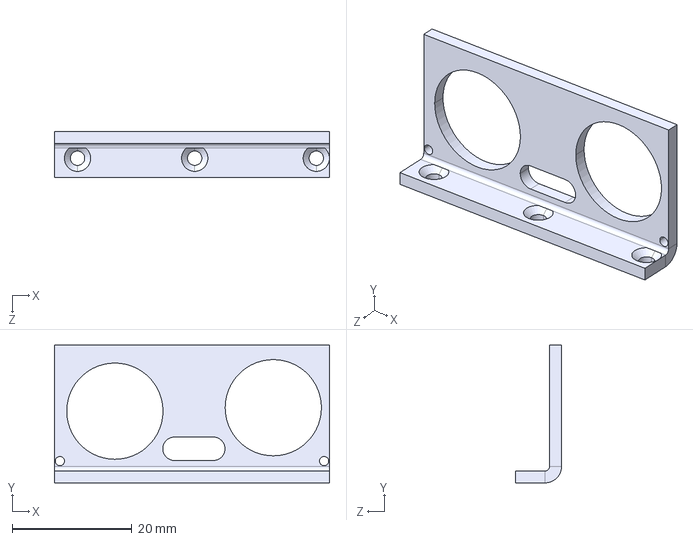
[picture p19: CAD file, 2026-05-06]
Design/GroupD3_2xUltrasonicSensor _6May2026.STEP
46.0 x 23.0 x 7.71 mm

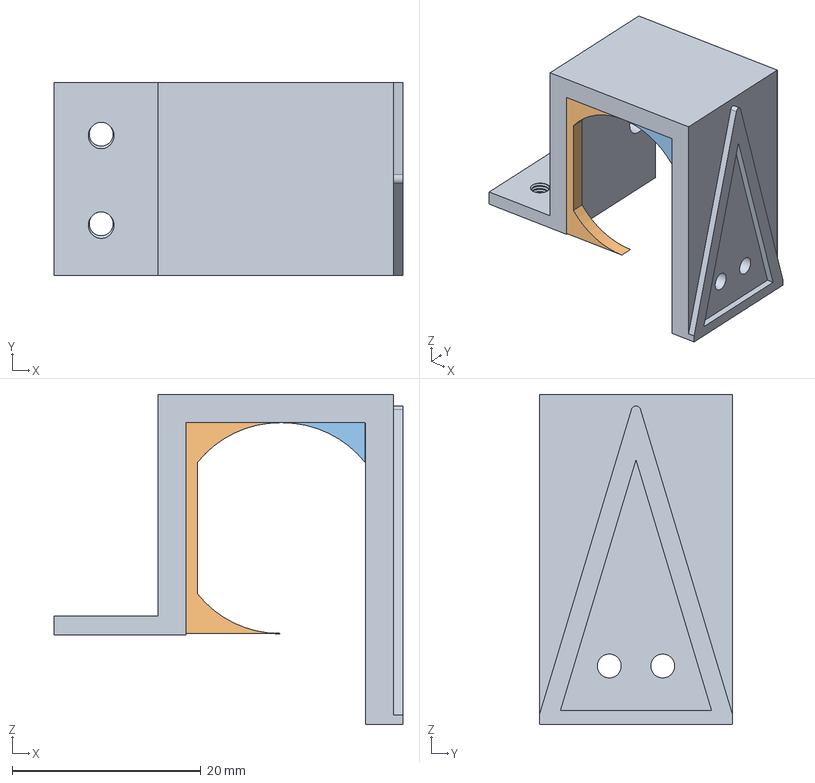
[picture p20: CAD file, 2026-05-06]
Design/GroupD3_2xMotorholderPart1_6May2026.step
37.0 x 20.5 x 35.0 mm

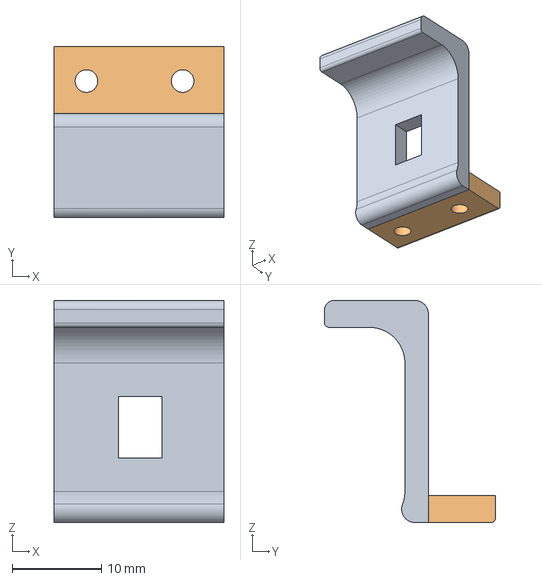
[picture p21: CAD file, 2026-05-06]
Design/GroupD3_2xMotorholderPart2_6May2026.step
19.0 x 19.1 x 24.8 mm

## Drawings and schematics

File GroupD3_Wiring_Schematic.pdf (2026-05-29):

A

1 | 2 | 3 | 4 | 5 | 6

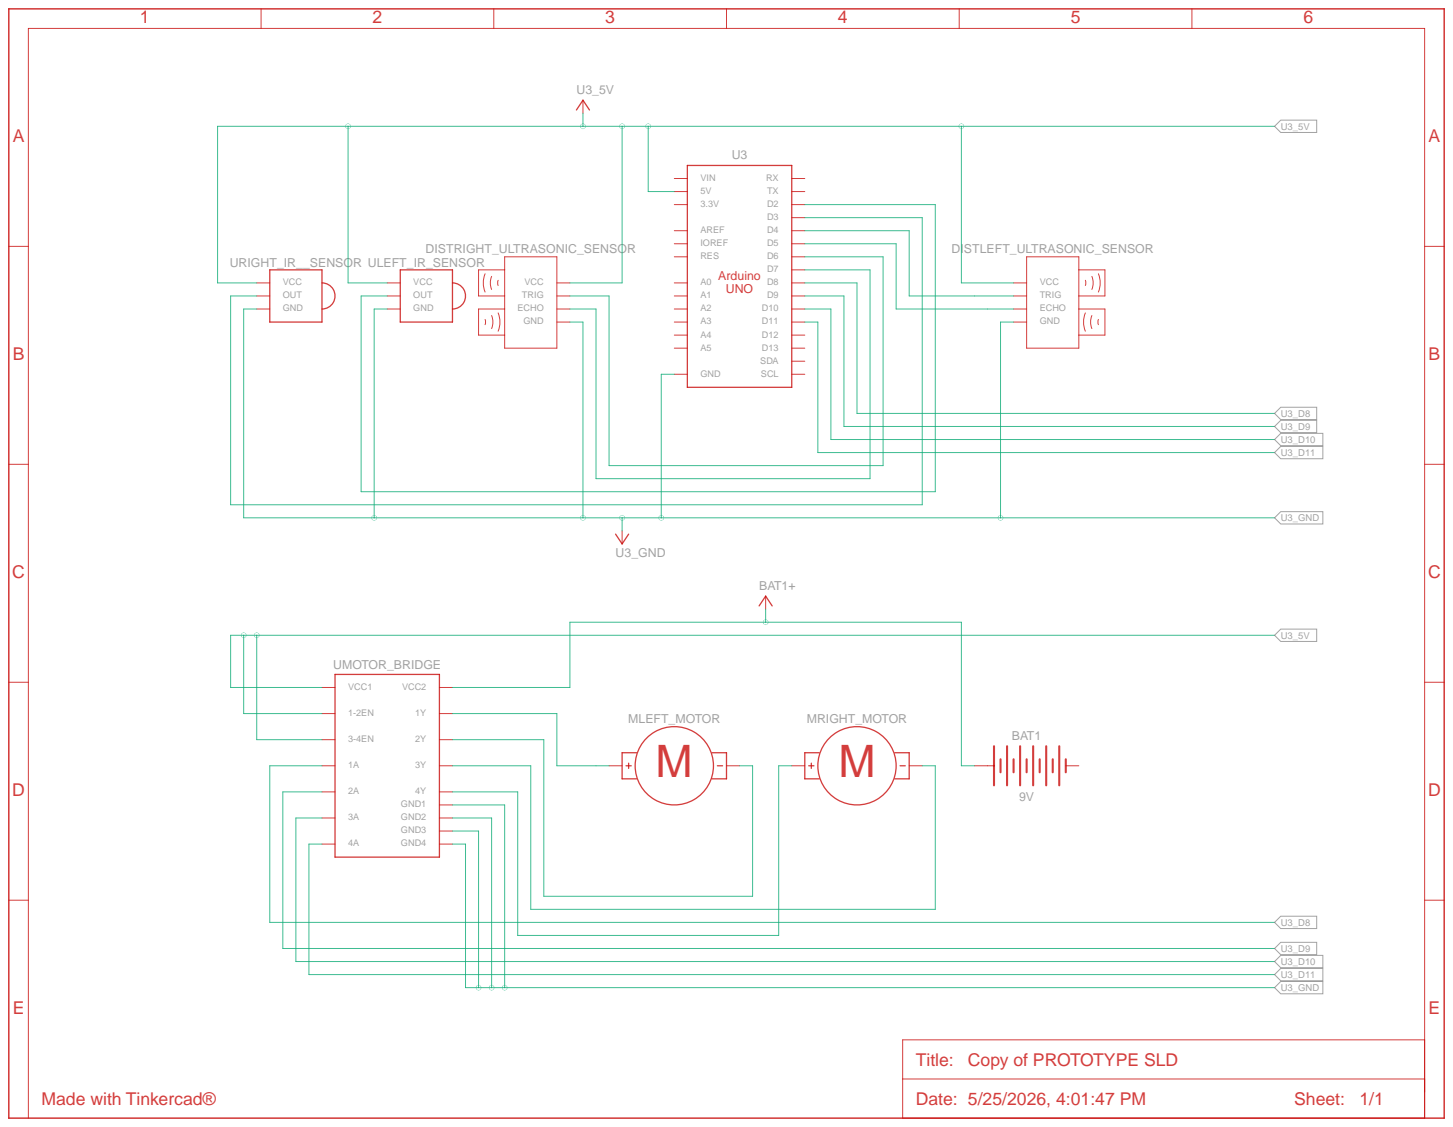
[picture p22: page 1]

Title: Copy of PROTOTYPE SLD

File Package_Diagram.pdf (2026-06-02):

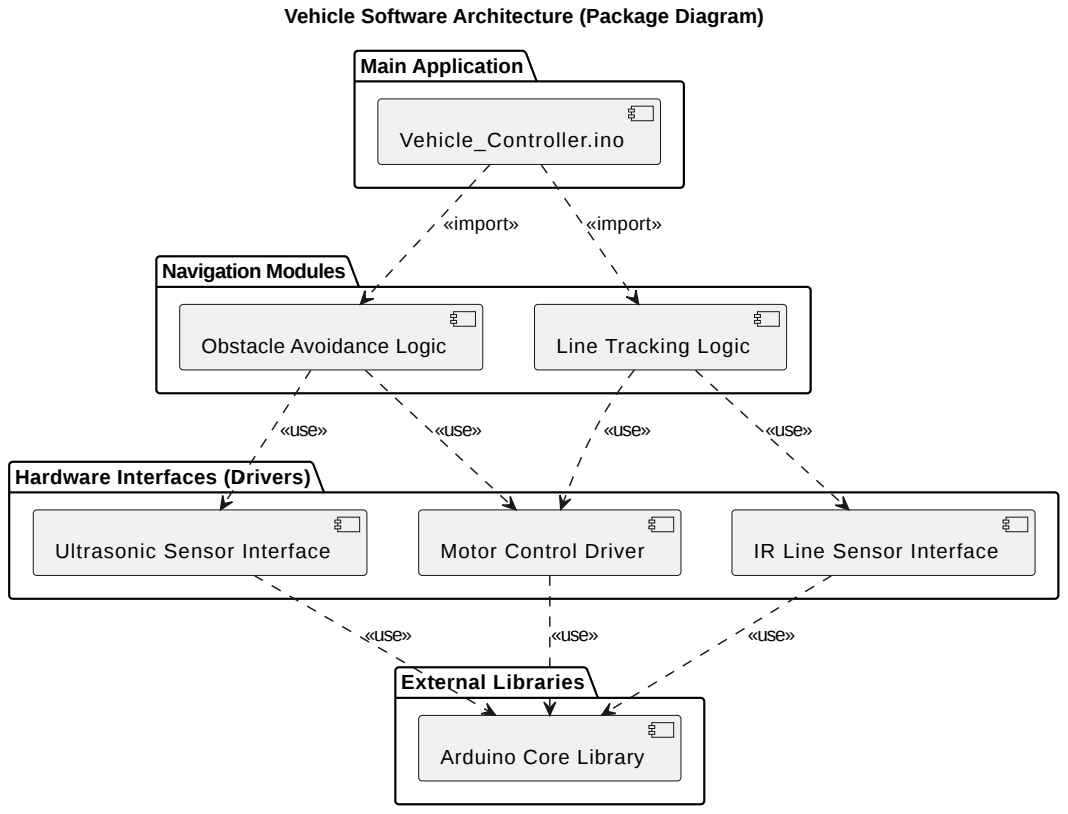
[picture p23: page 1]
External Libraries; Navigation Modules; Main Application; Ultrasonic Sensor Interface; Motor Control Driver; IR Line Sensor Interface; Obstacle Avoidance Logic; Line Tracking Logic; Vehicle_Controller.ino; «use»; «import»

Vehicle Software Architecture (Package Diagram)

Hardware Interfaces (Drivers)

Arduino Core Library

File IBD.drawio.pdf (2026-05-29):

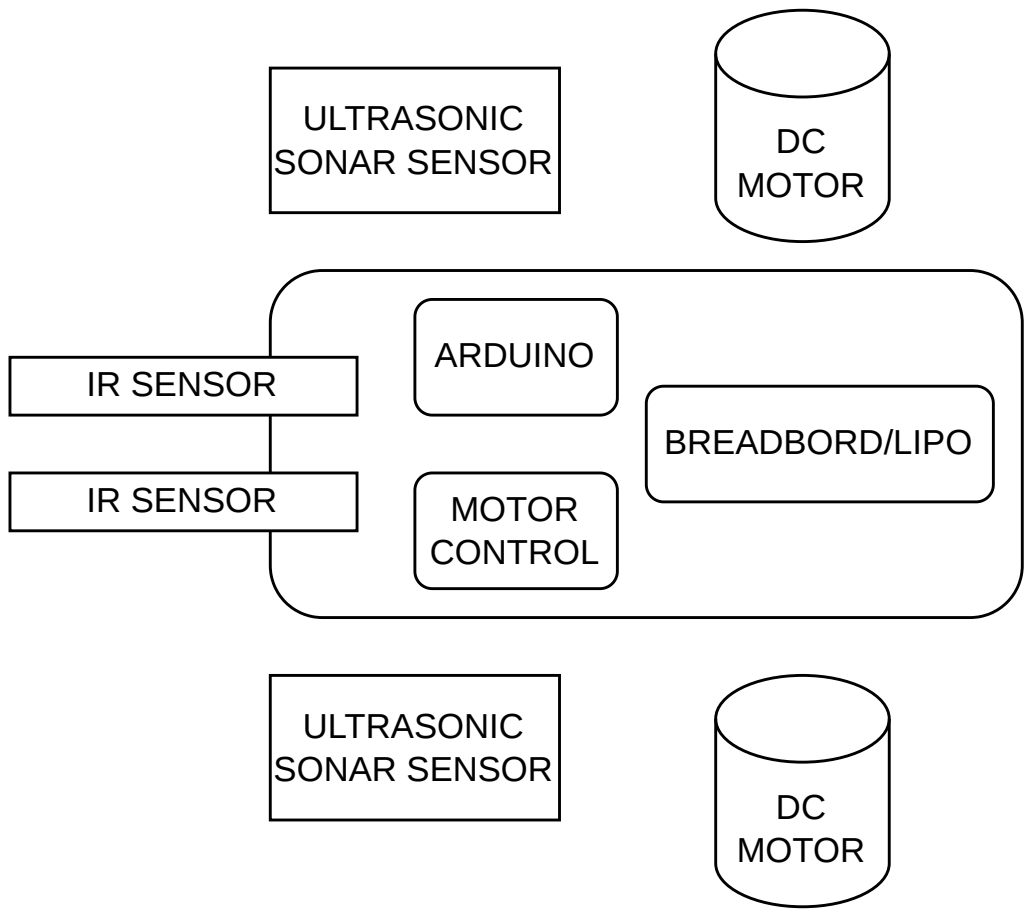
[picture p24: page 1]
IR SENSOR; ULTRASONIC SONAR SENSOR; DC MOTOR; ARDUINO; MOTOR CONTROL; BREADBORD/LIPO

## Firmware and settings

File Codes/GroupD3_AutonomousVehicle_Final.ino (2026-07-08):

// =============================================================================
// Milestone 2 Robot
// Line following + two-obstacle handling + ultrasonic avoidance
//
// This version UNDOES the "slow down at 20cm" obstacle-approach changes.
// Obstacle detection/trigger remains ONLY at 15 cm (OBSTACLE_DISTANCE_CM).
//
// Keeps the second obstacle behavior changes:
//  - timed 180° spin
//  - then spin until ANY sensor detects the line (stop immediately)
//  - pause 0.5s
//  - spin LEFT in place 0.5s
//  - drive forward briefly
//  - resume line following
// =============================================================================

#define IR_LINE_STATE      HIGH

// ---------------- LINE SENSOR PINS ----------------
#define IR_SENSOR_RIGHT 13
#define IR_SENSOR_LEFT  12

// ---------------- ULTRASONIC PINS ----------------
#define LEFT_TRIG  A2
#define LEFT_ECHO  A3
#define RIGHT_TRIG 2
#define RIGHT_ECHO 3

// ---------------- MOTOR PINS ----------------
const int enableRightMotor = 10;
const int rightMotorPin1 = 5;
const int rightMotorPin2 = 4;
const int enableLeftMotor = 11;
const int leftMotorPin1 = 7;
const int leftMotorPin2 = 6;

// ---------------- LINE FOLLOWING TUNING ----------------
#define SPEED_90(value) (((value) * 9 + 5) / 10)
#define TIME_FOR_90_SPEED(value) (((value) * 10 + 4) / 9)

#define MOTOR_SAFE_MIN_SPEED SPEED_90(65)
#define BASE_SPEED      SPEED_90(95)
#define MIN_SPEED       MOTOR_SAFE_MIN_SPEED
#define SEARCH_SPEED    MOTOR_SAFE_MIN_SPEED
#define LINE_MAX_SPEED  SPEED_90(125)

#define KP              0.90
#define FILTER          0.95
#define DEADZONE        0.25
#define CORNER_THR      0.65
#define STABLE_COUNT    3

// ---------------- OBSTACLE AVOIDANCE TUNING ----------------
#define OBSTACLE_DISTANCE_CM     15              // trigger avoidance ONLY at 15 cm
#define CLEAR_DISTANCE_CM        400
#define ECHO_TIMEOUT_US          9000UL
#define ULTRASONIC_SAMPLE_MS     40              // restored (no approach-slow feature)
#define OBSTACLE_COOLDOWN_MS     1200UL

#define BACK_UP_SPEED            SPEED_90(70)
#define AVOID_FORWARD_SPEED      SPEED_90(70)
#define AVOID_PARALLEL_FORWARD_SPEED SPEED_90(105)
#define AVOID_REJOIN_SPEED       SPEED_90(70)
#define AVOID_SPIN_SPEED         SPEED_90(95)

#define RECOVER_ARC_OUTER_SPEED  SPEED_90(95)
#define RECOVER_ARC_INNER_SPEED  MOTOR_SAFE_MIN_SPEED
#define REJOIN_ARC_OUTER_SPEED   SPEED_90(70)
#define REJOIN_ARC_INNER_SPEED   MOTOR_SAFE_MIN_SPEED

#define LINE_CENTER_SPIN_SPEED   MOTOR_SAFE_MIN_SPEED
#define REJOIN_HIT_BACKUP_SPEED  MOTOR_SAFE_MIN_SPEED

#define BACK_UP_10CM_MS          TIME_FOR_90_SPEED(640UL)
#define AVOID_TURN_OUT_MS        TIME_FOR_90_SPEED(300UL)
#define AVOID_SIDE_FORWARD_MS    TIME_FOR_90_SPEED(610UL)
#define AVOID_PARALLEL_TURN_MS   TIME_FOR_90_SPEED(300UL)
#define AVOID_PASS_OBJECT_MS     TIME_FOR_90_SPEED(456UL)
#define AVOID_RETURN_TURN_MS     TIME_FOR_90_SPEED(400UL)

#define LINE_REJOIN_TIMEOUT_MS   TIME_FOR_90_SPEED(2990UL)
#define RECOVERY_SWEEP_MS        TIME_FOR_90_SPEED(2220UL)
#define LINE_CENTER_TIMEOUT_MS   TIME_FOR_90_SPEED(1400UL)
#define REJOIN_HIT_BACKUP_MS     TIME_FOR_90_SPEED(200UL)

// ---------------- FIRST OBSTACLE REJOIN HOOK ----------------
#define FIRST_REJOIN_TURN90_SPEED        SPEED_90(75)
#define FIRST_REJOIN_TURN90_TIMEOUT_MS   TIME_FOR_90_SPEED(950UL)

// ---------------- SECOND OBSTACLE TURN (TIME-BASED + FIND LINE + ACTIONS) ----------------
#define TURN_180_RIGHT           true
#define TURN_180_SPEED           SPEED_90(61)
#define TURN_180_MS              TIME_FOR_90_SPEED(590UL)

#define SECOND_FIND_LINE_SPEED   SPEED_90(50)
#define SECOND_FIND_LINE_TIMEOUT TIME_FOR_90_SPEED(1800UL)

#define SECOND_LINE_HIT_PAUSE_MS         500UL
#define SECOND_LINE_HIT_SPIN_LEFT_MS     500UL
#define SECOND_LINE_HIT_SPIN_LEFT_SPEED  SPEED_90(60)

#define SECOND_REJOIN_FORWARD_MS    250UL
#define SECOND_REJOIN_FORWARD_SPEED SPEED_90(70)

#define SECOND_SETTLE_MS         120UL

// ---------------- DEBUG ----------------
#define DEBUG_SERIAL             1

// =============================================================================
// Structs + function prototypes
// =============================================================================
struct LineSample
{
  int leftRaw;
  int rightRaw;
  bool leftLine;
  bool rightLine;
};

LineSample readLineSensors();
void updateObstacleReadings();
bool obstacleDetected();
void followLine(LineSample line);
void avoidObstacle();
bool recoverLine(bool avoidedRight);
void performSecondObstacleTurn();
void resetLineTracking();
void searchForLine();
void driveForward(int speed);
void driveBackward(int speed);
bool lineDetected();
void rememberCurrentLineDirection();
bool arcTurnUntilLineAfterFirstObstacle(bool turnRight, int outerSpeed, int innerSpeed, unsigned long timeoutMs);
bool arcTurnUntilLine(bool turnRight, int outerSpeed, int innerSpeed, unsigned long timeoutMs);
void arcTurnRobot(bool turnRight, int outerSpeed, int innerSpeed);
void spinRobot(bool turnRight, int speed);
void spinRobotFor(bool turnRight, int speed, unsigned long durationMs);
int getDistance(int trigPin, int echoPin);
void rotateMotor(int rightMotorSpeed, int leftMotorSpeed);

bool hookLeftOntoLine90(unsigned long timeoutMs);
bool spinUntilLineDetected(bool turnRight, int speed, unsigned long timeoutMs);

// =============================================================================
// Globals
// =============================================================================
int lastDirection = 0;
float filteredError = 0;

int lastL = -1;
int lastR = -1;
int stableCount = 0;

int lastRightSpeed = 0;
int lastLeftSpeed = 0;

int lastLeftDistance = CLEAR_DISTANCE_CM;
int lastRightDistance = CLEAR_DISTANCE_CM;

int confirmedObstacleCount = 0;

unsigned long lastUltrasonicReadMs = 0;
unsigned long ignoreObstacleUntilMs = 0;
unsigned long lastSerialPrintMs = 0;

// =============================================================================
void setup()
{
#if DEBUG_SERIAL
  Serial.begin(9600);
#endif

  pinMode(enableRightMotor, OUTPUT);
  pinMode(enableLeftMotor, OUTPUT);

  pinMode(rightMotorPin1, OUTPUT);
  pinMode(rightMotorPin2, OUTPUT);
  pinMode(leftMotorPin1, OUTPUT);
  pinMode(leftMotorPin2, OUTPUT);

  pinMode(IR_SENSOR_LEFT, INPUT);
  pinMode(IR_SENSOR_RIGHT, INPUT);

  pinMode(LEFT_TRIG, OUTPUT);
  pinMode(LEFT_ECHO, INPUT);
  pinMode(RIGHT_TRIG, OUTPUT);
  pinMode(RIGHT_ECHO, INPUT);

  digitalWrite(LEFT_TRIG, LOW);
  digitalWrite(RIGHT_TRIG, LOW);

  rotateMotor(0, 0);
}

// =============================================================================
void loop()
{
  updateObstacleReadings();
  LineSample line = readLineSensors();

#if DEBUG_SERIAL
  if (millis() - lastSerialPrintMs > 500)
  {
    lastSerialPrintMs = millis();
    Serial.print("IR L: ");
    Serial.print(line.leftRaw);
    Serial.print(" | IR R: ");
    Serial.print(line.rightRaw);
    Serial.print(" || US L: ");
    Serial.print(lastLeftDistance);
    Serial.print(" cm | US R: ");
    Serial.print(lastRightDistance);
    Serial.println(" cm");
  }
#endif

  if (obstacleDetected())
  {
    avoidObstacle();
    return;
  }

  followLine(line);
}

// =============================================================================
LineSample readLineSensors()
{
  LineSample line;
  line.leftRaw = digitalRead(IR_SENSOR_LEFT);
  line.rightRaw = digitalRead(IR_SENSOR_RIGHT);
  line.leftLine = (line.leftRaw == IR_LINE_STATE);
  line.rightLine = (line.rightRaw == IR_LINE_STATE);
  return line;
}

// =============================================================================
void followLine(LineSample line)
{
  int L = line.leftLine ? 1 : 0;
  int R = line.rightLine ? 1 : 0;

  if (L == lastL && R == lastR) stableCount++;
  else stableCount = 1;

  lastL = L;
  lastR = R;

  if (stableCount < STABLE_COUNT)
  {
    rotateMotor(lastRightSpeed, lastLeftSpeed);
    return;
  }

  int error;
  if (L == 1 && R == 1)
  {
    error = 0;
    lastDirection = 0;
  }
  else if (L == 1 && R == 0)
  {
    error = -1;
    lastDirection = -1;
  }
  else if (L == 0 && R == 1)
  {
    error = 1;
    lastDirection = 1;
  }
  else
  {
    searchForLine();
    return;
  }

  filteredError = (FILTER * filteredError) + ((1.0 - FILTER) * error);
  if (abs(filteredError) < DEADZONE) filteredError = 0;

  if (abs(filteredError) > CORNER_THR)
  {
    if (filteredError > 0)
    {
      lastRightSpeed = MOTOR_SAFE_MIN_SPEED;
      lastLeftSpeed  = LINE_MAX_SPEED;
    }
    else
    {
      lastRightSpeed = LINE_MAX_SPEED;
      lastLeftSpeed  = MOTOR_SAFE_MIN_SPEED;
    }
    rotateMotor(lastRightSpeed, lastLeftSpeed);
    return;
  }

  float turn = filteredError * KP;

  int rightSpeed = (int)(BASE_SPEED * (1.0 - turn));
  int leftSpeed  = (int)(BASE_SPEED * (1.0 + turn));

  int penalty = (int)(abs(turn) * 6);
  rightSpeed -= penalty;
  leftSpeed  -= penalty;

  rightSpeed = constrain(rightSpeed, MIN_SPEED, LINE_MAX_SPEED);
  leftSpeed = constrain(leftSpeed, MIN_SPEED, LINE_MAX_SPEED);

  lastRightSpeed = rightSpeed;
  lastLeftSpeed = leftSpeed;

  rotateMotor(rightSpeed, leftSpeed);
}

// =============================================================================
void updateObstacleReadings()
{
  unsigned long now = millis();
  if (now - lastUltrasonicReadMs < ULTRASONIC_SAMPLE_MS) return;

  lastUltrasonicReadMs = now;

  lastLeftDistance = getDistance(LEFT_TRIG, LEFT_ECHO);
  delay(5);
  lastRightDistance = getDistance(RIGHT_TRIG, RIGHT_ECHO);
}

// =============================================================================
bool obstacleDetected()
{
  if (millis() < ignoreObstacleUntilMs) return false;

  return (lastLeftDistance <= OBSTACLE_DISTANCE_CM ||
          lastRightDistance <= OBSTACLE_DISTANCE_CM);
}

// =============================================================================
void avoidObstacle()
{
  rotateMotor(0, 0);
  delay(80);

  int freshLeft = getDistance(LEFT_TRIG, LEFT_ECHO);
  delay(5);
  int freshRight = getDistance(RIGHT_TRIG, RIGHT_ECHO);

  lastLeftDistance = freshLeft;
  lastRightDistance = freshRight;

  if (freshLeft > OBSTACLE_DISTANCE_CM && freshRight > OBSTACLE_DISTANCE_CM)
  {
    resetLineTracking();
    return;
  }

  confirmedObstacleCount++;

  // NEW LOGIC: When count hits 2, reset it immediately and do the turn.
  if (confirmedObstacleCount == 2)
  {
    confirmedObstacleCount = 0;
    performSecondObstacleTurn();
    return;
  }

  bool avoidRight = false;

#if DEBUG_SERIAL
  Serial.print("First obstacle detected. Clearance L/R: ");
  Serial.print(freshLeft);
  Serial.print(" cm / ");
  Serial.print(freshRight);
  Serial.println(" cm. Avoiding left.");
#endif

  driveBackward(BACK_UP_SPEED);
  delay(BACK_UP_10CM_MS);
  rotateMotor(0, 0);
  delay(80);

  spinRobotFor(avoidRight, AVOID_SPIN_SPEED, AVOID_TURN_OUT_MS);

  driveForward(AVOID_FORWARD_SPEED);
  delay(AVOID_SIDE_FORWARD_MS);
  rotateMotor(0, 0);
  delay(50);

  spinRobotFor(!avoidRight, AVOID_SPIN_SPEED, AVOID_PARALLEL_TURN_MS);

  driveForward(AVOID_PARALLEL_FORWARD_SPEED);
  delay(AVOID_PASS_OBJECT_MS);
  rotateMotor(0, 0);
  delay(50);

  rotateMotor(0, 0);
  delay(50);
  spinRobotFor(!avoidRight, AVOID_SPIN_SPEED, AVOID_RETURN_TURN_MS);

  bool lineRecovered = arcTurnUntilLineAfterFirstObstacle(!avoidRight,
                                                         REJOIN_ARC_OUTER_SPEED,
                                                         REJOIN_ARC_INNER_SPEED,
                                                         LINE_REJOIN_TIMEOUT_MS);

  if (!lineRecovered)
  {
    lineRecovered = recoverLine(avoidRight);
  }

  rotateMotor(0, 0);

  ignoreObstacleUntilMs = millis() + OBSTACLE_COOLDOWN_MS;
  resetLineTracking();
  lastDirection = lineRecovered ? 0 : 1;
}

// =============================================================================
void performSecondObstacleTurn()
{
#if DEBUG_SERIAL
  Serial.println("Second obstacle: timed 180 + spin until line + pause + left spin + forward");
#endif

  rotateMotor(0, 0);
  delay(120);

  spinRobotFor(TURN_180_RIGHT, TURN_180_SPEED, TURN_180_MS);

  bool found = spinUntilLineDetected(TURN_180_RIGHT, SECOND_FIND_LINE_SPEED, SECOND_FIND_LINE_TIMEOUT);

#if DEBUG_SERIAL
  Serial.print("Second obstacle line reacquire: ");
  Serial.println(found ? "FOUND" : "TIMEOUT");
#endif

  if (found)
  {
    rotateMotor(0, 0);
    delay(SECOND_LINE_HIT_PAUSE_MS);

    // spin LEFT for 0.5s
    spinRobot(false, SECOND_LINE_HIT_SPIN_LEFT_SPEED);
    delay(SECOND_LINE_HIT_SPIN_LEFT_MS);
    rotateMotor(0, 0);
    delay(60);

    driveForward(SECOND_REJOIN_FORWARD_SPEED);
    delay(SECOND_REJOIN_FORWARD_MS);

    rotateMotor(0, 0);
    delay(80);
  }
  else
  {
    rotateMotor(0, 0);
    delay(SECOND_SETTLE_MS);
  }

  ignoreObstacleUntilMs = millis() + OBSTACLE_COOLDOWN_MS;
  resetLineTracking();
  lastDirection = 0;
}

// =============================================================================
bool spinUntilLineDetected(bool turnRight, int speed, unsigned long timeoutMs)
{
  unsigned long start = millis();
  while (millis() - start < timeoutMs)
  {
    if (lineDetected())
    {
      rotateMotor(0, 0);
      return true;
    }
    spinRobot(turnRight, speed);
    delay(5);
  }
  rotateMotor(0, 0);
  return false;
}

// =============================================================================
bool recoverLine(bool avoidedRight)
{
  bool lineIsOnLeft = avoidedRight;

  if (arcTurnUntilLine(!lineIsOnLeft, RECOVER_ARC_OUTER_SPEED, RECOVER_ARC_INNER_SPEED, RECOVERY_SWEEP_MS))
    return true;

  if (arcTurnUntilLine(lineIsOnLeft, RECOVER_ARC_OUTER_SPEED, RECOVER_ARC_INNER_SPEED, RECOVERY_SWEEP_MS))
    return true;

  rotateMotor(0, 0);
  return false;
}

// =============================================================================
void resetLineTracking()
{
  filteredError = 0;
  lastL = -1;
  lastR = -1;
  stableCount = 0;
  lastRightSpeed = 0;
  lastLeftSpeed = 0;
}

// =============================================================================
void searchForLine()
{
  if (lastDirection < 0) rotateMotor(-SEARCH_SPEED, SEARCH_SPEED);
  else if (lastDirection > 0) rotateMotor(SEARCH_SPEED, -SEARCH_SPEED);
  else rotateMotor(SEARCH_SPEED, -SEARCH_SPEED);
}

// =============================================================================
void driveForward(int speed)
{
  rotateMotor(speed, speed);
}

// =============================================================================
void driveBackward(int speed)
{
  rotateMotor(-speed, -speed);
}

// =============================================================================
bool lineDetected()
{
  LineSample line = readLineSensors();
  return (line.leftLine || line.rightLine);
}

// =============================================================================
bool hookLeftOntoLine90(unsigned long timeoutMs)
{
  rotateMotor(0, 0);
  delay(70);

  driveBackward(REJOIN_HIT_BACKUP_SPEED);
  delay(REJOIN_HIT_BACKUP_MS);

  rotateMotor(0, 0);
  delay(70);

  unsigned long start = millis();
  while (millis() - start < timeoutMs)
  {
    LineSample line = readLineSensors();

    if (line.leftLine && line.rightLine)
    {
      rotateMotor(0, 0);
      delay(80);
      lastDirection = 0;
      return true;
    }

    spinRobot(false, FIRST_REJOIN_TURN90_SPEED);
    delay(5);
  }

  rotateMotor(0, 0);
  delay(80);
  rememberCurrentLineDirection();
  LineSample l = readLineSensors();
  return (l.leftLine || l.rightLine);
}

// =============================================================================
void rememberCurrentLineDirection()
{
  LineSample line = readLineSensors();
  if (line.leftLine && !line.rightLine) lastDirection = -1;
  else if (!line.leftLine && line.rightLine) lastDirection = 1;
  else if (line.leftLine && line.rightLine) lastDirection = 0;
}

// =============================================================================
bool arcTurnUntilLineAfterFirstObstacle(bool turnRight, int outerSpeed, int innerSpeed, unsigned long timeoutMs)
{
  unsigned long startTime = millis();
  while (millis() - startTime < timeoutMs)
  {
    if (lineDetected())
    {
      return hookLeftOntoLine90(FIRST_REJOIN_TURN90_TIMEOUT_MS);
    }
    arcTurnRobot(turnRight, outerSpeed, innerSpeed);
    delay(5);
  }
  return false;
}

// =============================================================================
bool arcTurnUntilLine(bool turnRight, int outerSpeed, int innerSpeed, unsigned long timeoutMs)
{
  unsigned long startTime = millis();
  while (millis() - startTime < timeoutMs)
  {
    if (lineDetected())
    {
      rememberCurrentLineDirection();
      return true;
    }
    arcTurnRobot(turnRight, outerSpeed, innerSpeed);
    delay(5);
  }
  return false;
}

// =============================================================================
void arcTurnRobot(bool turnRight, int outerSpeed, int innerSpeed)
{
  if (turnRight) rotateMotor(innerSpeed, outerSpeed);
  else rotateMotor(outerSpeed, innerSpeed);
}

// =============================================================================
void spinRobot(bool turnRight, int speed)
{
  if (turnRight) rotateMotor(speed, -speed);
  else rotateMotor(-speed, speed);
}

// =============================================================================
void spinRobotFor(bool turnRight, int speed, unsigned long durationMs)
{
  spinRobot(turnRight, speed);
  delay(durationMs);
  rotateMotor(0, 0);
  delay(50);
}

// =============================================================================
int getDistance(int trigPin, int echoPin)
{
  digitalWrite(trigPin, LOW);
  delayMicroseconds(2);
  digitalWrite(trigPin, HIGH);
  delayMicroseconds(10);
  digitalWrite(trigPin, LOW);

  long duration = pulseIn(echoPin, HIGH, ECHO_TIMEOUT_US);
  if (duration == 0) return CLEAR_DISTANCE_CM;

  int distance = (int)(duration * 0.0343 / 2.0);
  if (distance <= 0 || distance > CLEAR_DISTANCE_CM) return CLEAR_DISTANCE_CM;
  return distance;
}

// =============================================================================
void rotateMotor(int rightMotorSpeed, int leftMotorSpeed)
{
  if (rightMotorSpeed > 0)
  {
    digitalWrite(rightMotorPin1, HIGH);
    digitalWrite(rightMotorPin2, LOW);
  }
  else if (rightMotorSpeed < 0)
  {
    digitalWrite(rightMotorPin1, LOW);
    digitalWrite(rightMotorPin2, HIGH);
  }
  else
  {
    digitalWrite(rightMotorPin1, LOW);
    digitalWrite(rightMotorPin2, LOW);
  }

  if (leftMotorSpeed > 0)
  {
    digitalWrite(leftMotorPin1, HIGH);
    digitalWrite(leftMotorPin2, LOW);
  }
  else if (leftMotorSpeed < 0)
  {
    digitalWrite(leftMotorPin1, LOW);
    digitalWrite(leftMotorPin2, HIGH);
  }
  else
  {
    digitalWrite(leftMotorPin1, LOW);
    digitalWrite(leftMotorPin2, LOW);
  }

  int rightPwm = constrain(abs(rightMotorSpeed), 0, 255);
  int leftPwm  = constrain(abs(leftMotorSpeed), 0, 255);

  if (rightPwm > 0 && rightPwm < MOTOR_SAFE_MIN_SPEED) rightPwm = MOTOR_SAFE_MIN_SPEED;
  if (leftPwm  > 0 && leftPwm  < MOTOR_SAFE_MIN_SPEED) leftPwm  = MOTOR_SAFE_MIN_SPEED;

  analogWrite(enableRightMotor, rightPwm);
  analogWrite(enableLeftMotor, leftPwm);
}

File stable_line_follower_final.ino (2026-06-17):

// =============================================================================
// Ultra Stable Line Follower (Noise Removal + Stable Tracking)
// =============================================================================

#define IR_SENSOR_RIGHT 13
#define IR_SENSOR_LEFT  12

// ---------------- MOTOR PINS ----------------
const int enableRightMotor = 10;
const int rightMotorPin1 = 5;
const int rightMotorPin2 = 4;

const int enableLeftMotor = 11;
const int leftMotorPin1 = 7;
const int leftMotorPin2 = 6;

// ---------------- TUNING ----------------
#define BASE_SPEED     128
#define MIN_SPEED      100
#define SEARCH_SPEED   65

#define KP             1.05
#define FILTER         0.995     // stronger smoothing (important fix)
#define DEADZONE       0.12
#define CORNER_THR     0.65

// ---------------- INPUT STABILITY ----------------
#define STABLE_COUNT   3   // must see same reading 3 times

int lastDirection = 0;
float filteredError = 0;

int lastL = -1, lastR = -1;
int stableCount = 0;

int lastRightSpeed = 0;
int lastLeftSpeed = 0;

// =============================================================================
void setup()
{
  TCCR0B = (TCCR0B & B11111000) | B00000010;

  pinMode(enableRightMotor, OUTPUT);
  pinMode(enableLeftMotor, OUTPUT);

  pinMode(rightMotorPin1, OUTPUT);
  pinMode(rightMotorPin2, OUTPUT);

  pinMode(leftMotorPin1, OUTPUT);
  pinMode(leftMotorPin2, OUTPUT);

  pinMode(IR_SENSOR_LEFT, INPUT);
  pinMode(IR_SENSOR_RIGHT, INPUT);

  rotateMotor(0, 0);
}

// =============================================================================
void loop()
{
  int L = digitalRead(IR_SENSOR_LEFT);
  int R = digitalRead(IR_SENSOR_RIGHT);

  // ---------------- NOISE FILTER (KEY FIX) ----------------
  if (L == lastL && R == lastR)
    stableCount++;
  else
    stableCount = 0;

  lastL = L;
  lastR = R;

  if (stableCount < STABLE_COUNT)
  {
    // hold last motor output → removes twitching completely
    rotateMotor(lastRightSpeed, lastLeftSpeed);
    return;
  }

  int error;

  // ---------------- LINE STATE ----------------
  if (L == HIGH && R == HIGH)
  {
    error = 0;
    lastDirection = 0;
  }
  else if (L == HIGH && R == LOW)
  {
    error = -1;
    lastDirection = -1;
  }
  else if (L == LOW && R == HIGH)
  {
    error = 1;
    lastDirection = 1;
  }
  else
  {
    searchForLine();
    return;
  }

  // ---------------- SMOOTH FILTER ----------------
  filteredError = (FILTER * filteredError) + ((1 - FILTER) * error);

  if (abs(filteredError) < DEADZONE)
    filteredError = 0;

  // ---------------- CORNER MODE ----------------
  if (abs(filteredError) > CORNER_THR)
  {
    if (filteredError > 0)
    {
      lastRightSpeed = 35;
      lastLeftSpeed = 150;
    }
    else
    {
      lastRightSpeed = 150;
      lastLeftSpeed = 35;
    }

    rotateMotor(lastRightSpeed, lastLeftSpeed);
    return;
  }

  // ---------------- TRACK MODE ----------------
  float turn = filteredError * KP;

  int rightSpeed = BASE_SPEED * (1.0 - turn);
  int leftSpeed  = BASE_SPEED * (1.0 + turn);

  int penalty = abs(turn) * 6;

  rightSpeed -= penalty;
  leftSpeed  -= penalty;

  rightSpeed = constrain(rightSpeed, MIN_SPEED, 140);
  leftSpeed  = constrain(leftSpeed, MIN_SPEED, 140);

  lastRightSpeed = rightSpeed;
  lastLeftSpeed  = leftSpeed;

  rotateMotor(rightSpeed, leftSpeed);
}

// =============================================================================
void searchForLine()
{
  if (lastDirection < 0)
    rotateMotor(-SEARCH_SPEED, SEARCH_SPEED);
  else if (lastDirection > 0)
    rotateMotor(SEARCH_SPEED, -SEARCH_SPEED);
  else
    rotateMotor(SEARCH_SPEED, SEARCH_SPEED);
}

// =============================================================================
void rotateMotor(int rightMotorSpeed, int leftMotorSpeed)
{
  if (rightMotorSpeed > 0)
  {
    digitalWrite(rightMotorPin1, HIGH);
    digitalWrite(rightMotorPin2, LOW);
  }
  else if (rightMotorSpeed < 0)
  {
    digitalWrite(rightMotorPin1, LOW);
    digitalWrite(rightMotorPin2, HIGH);
  }
  else
  {
    digitalWrite(rightMotorPin1, LOW);
    digitalWrite(rightMotorPin2, LOW);
  }

  if (leftMotorSpeed > 0)
  {
    digitalWrite(leftMotorPin1, HIGH);
    digitalWrite(leftMotorPin2, LOW);
  }
  else if (leftMotorSpeed < 0)
  {
    digitalWrite(leftMotorPin1, LOW);
    digitalWrite(leftMotorPin2, HIGH);
  }
  else
  {
    digitalWrite(leftMotorPin1, LOW);
    digitalWrite(leftMotorPin2, LOW);
  }

  analogWrite(enableRightMotor, constrain(abs(rightMotorSpeed), 0, 255));
  analogWrite(enableLeftMotor, constrain(abs(leftMotorSpeed), 0, 255));
}

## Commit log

2026-05-06 Create Motor_Holder
2026-07-07 Add files via upload
    Loops between the two obstacles avoidance ways
    [milestone2_looping.ino]
